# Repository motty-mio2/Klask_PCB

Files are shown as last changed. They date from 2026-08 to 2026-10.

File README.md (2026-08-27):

# Klask PCB

This repository contains the KiCad project files for **Klask PCB**, a custom Arduino Uno R3 shield designed to control stepper motors and limit switches for manipulating a **Klask** board game.

## Overview

**Klask PCB** is a hardware interface designed to automate or robotize the board game "Klask". It uses stepper motors to move the game magnets under the board. 

The shield drives two stepper motors (X and Y axes) using Pololu-style DRV8825 stepper driver modules and processes signals from homing limit switches to align the axes. Additionally, it integrates a power sense circuit to detect external 12V supply and is powered efficiently via a USB-PD Trigger Module.

---

## Features

- **Dual Axis Control**: Supports two DRV8825 stepper motor driver modules for X and Y axes.
- **Homing Support**: Hardware inputs for X and Y axis limit switches to perform auto-calibration (0-point homing).
- **USB-PD Powered**: Powered via an external 12V supply using a USB-PD Trigger Module.
- **Power Detection (Power Sense)**: Built-in voltage divider and noise-filtering circuit to safely detect whether the 12V motor power supply is active using the Arduino `D10` pin.
- **Visual Indicator**: LED indicator to show the status of the 12V power supply.
- **Minimalist Arduino Shield**: Uses only the Digital headers (10-pin and 8-pin) of the Arduino Uno R3 to minimize interference and pin usage.

---

## Bill of Materials (BOM)

Below is the list of components required to assemble the Klask PCB.

| Component | Designator | Qty | Description / Footprint |
| --- | --- | --- | --- |
| **DRV8825 Stepper Driver Module** | A1, A2 | 2 | Pololu Breakout board style stepper driver |
| **Arduino UNO R3** | A3 | 1 | Microcontroller board (acts as base) |
| **USB-PD Trigger Module** | — | 1 | Set to 12V output mode |
| **10-pin Pin Header** | — | 1 | 2.54mm pitch (for Arduino Digital High header) |
| **8-pin Pin Header** | — | 1 | 2.54mm pitch (for Arduino Digital Low header) |
| **8-pin Pin Socket** | — | 4 | 2.54mm pitch (sockets for DRV8825 modules) |
| **LED** | D1 | 1 | 3mm THT LED (Power/12V Status Indicator) |
| **2.54mm Terminal Block** | J1, J2, J3, J4, J5, SW4, SW5 | 7 | XY308-2.54-2P (For MotXA, MotXB, MotYA, MotYB, 12V, SWX, SWY) |
| **510 Ω Resistor** | R1 | 1 | THT Resistor (LED current limiting) |
| **180 Ω Resistor** | R2 | 1 | THT Resistor (Power sensing voltage divider) |
| **0.1 µF Capacitor** | C1 | 1 | Ceramic Capacitor THT (Power sense noise filter) |
| **100 µF Capacitor** | C3, C4 | 2 | Electrolytic Capacitor THT (Motor power decoupling) |

*Note: SW2 (SW_A) and SW3 (SW_B) are present on the PCB layout for potential UI expansion but are not populated in this build.*

---

## Pin Mapping

The Arduino Uno R3 digital pins are mapped to the stepper drivers, limit switches, and power sense circuit as follows:

### Stepper Motor Drivers (DRV8825)
| Signal Name | Arduino Uno Pin | DRV8825 Pin | Description |
| --- | --- | --- | --- |
| `/MX_STEP` | `D8` | `STEP` (A1) | X-axis step control pulse |
| `/MX_DIR` | `D9` | `DIR` (A1) | X-axis rotation direction |
| `/MY_STEP` | `D4` | `STEP` (A2) | Y-axis step control pulse |
| `/MY_DIR` | `D5` | `DIR` (A2) | Y-axis rotation direction |
| `/nEN` | `D3` | `~{RST}`, `~{SLP}` (A1, A2) | Driver enable (Reset / Sleep control) |
| `/M0` | `D0 / RX` | `M0` (A1, A2) | Microstep configuration bit 0 |
| `/M1` | `D1 / TX` | `M1` (A1, A2) | Microstep configuration bit 1 |
| `/M2` | `D2` | `M2` (A1, A2) | Microstep configuration bit 2 |

### Limit Switches & Sensors
| Signal Name | Arduino Uno Pin | PCB Connector | Description |
| --- | --- | --- | --- |
| `/SW_X` | `A5` (Digital I/O) | `SW4` | X-axis homing limit switch (Active Low) |
| `/SW_Y` | `A4` (Digital I/O) | `SW5` | Y-axis homing limit switch (Active Low) |
| `GND` | `GND` | `SW4`, `SW5` | Common Ground for switches |

### Power Sense & Feedback
| Signal Name | Arduino Uno Pin | Related Parts | Description |
| --- | --- | --- | --- |
| `/A0` | `D10` | `D1`, `R1`, `R2`, `C1` | Input pin to sense if 12V is connected (HIGH = 12V Present) |

---

## Hardware Connection & Assembly

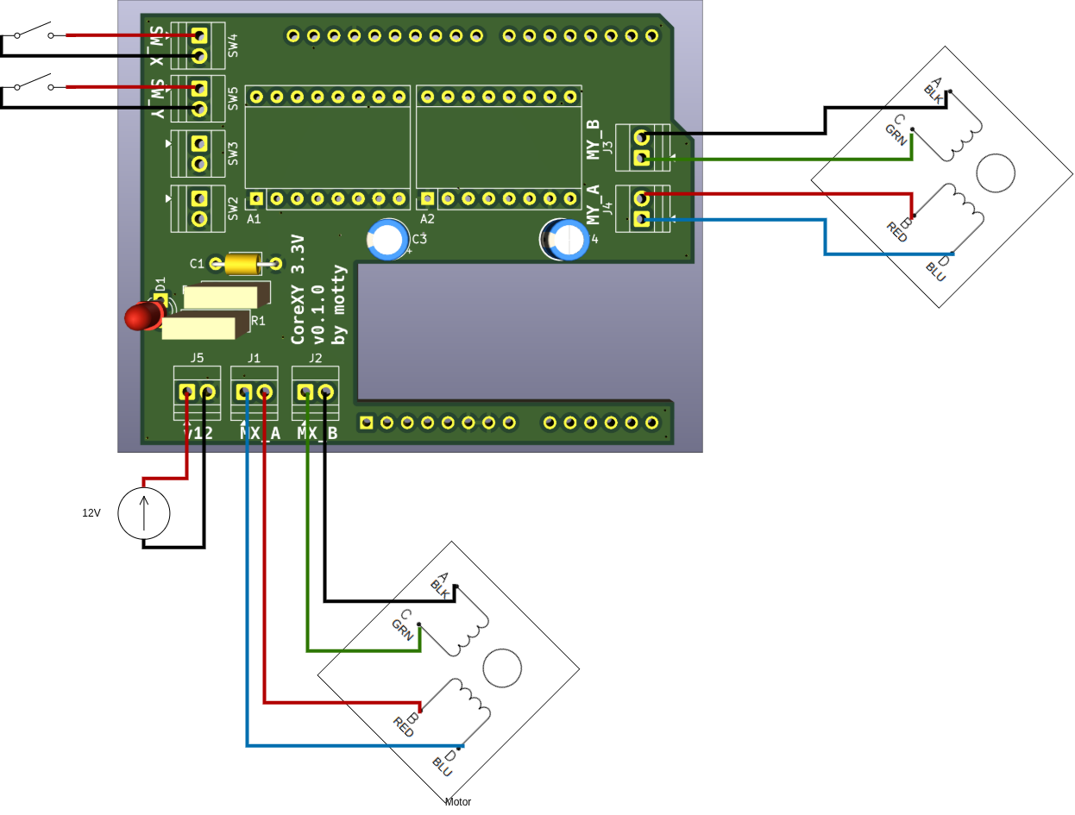
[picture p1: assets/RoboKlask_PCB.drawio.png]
Conceptual Wiring Diagram


1. **Terminal Blocks Wiring**:
   - **`J5` (12V Input)**: Connect the 12V and GND outputs from the **USB-PD Trigger Module**.
   - **`J1` & `J2`**: Connect to the X-axis stepper motor coils (Phase A to `J1`, Phase B to `J2`).
   - **`J3` & `J4`**: Connect to the Y-axis stepper motor coils (Phase A to `J3`, Phase B to `J4`).
   - **`SW4` & `SW5`**: Connect to the X-axis and Y-axis limit switches.
2. **Arduino Uno Mounting**:
   - Solder the 10-pin and 8-pin male headers to the digital side of the shield.
   - Solder the power sense circuit parts (`D1`, `R1`, `R2`, `C1`) and decoupling capacitors (`C3`, `C4`).
   - Stack the shield onto the Arduino Uno R3.
3. **Stepper Drivers**:
   - Solder the 8x4 female pin sockets onto the shield.
   - Insert the DRV8825 stepper driver modules into the sockets. Make sure the orientation is correct (VMOT/GND pin alignment).

---

## License

This project is licensed under the **CC BY-SA 4.0** (Creative Commons Attribution-ShareAlike 4.0 International) license. Feel free to share, copy, and modify, provided appropriate credit is given and any derivative works are distributed under the same license.

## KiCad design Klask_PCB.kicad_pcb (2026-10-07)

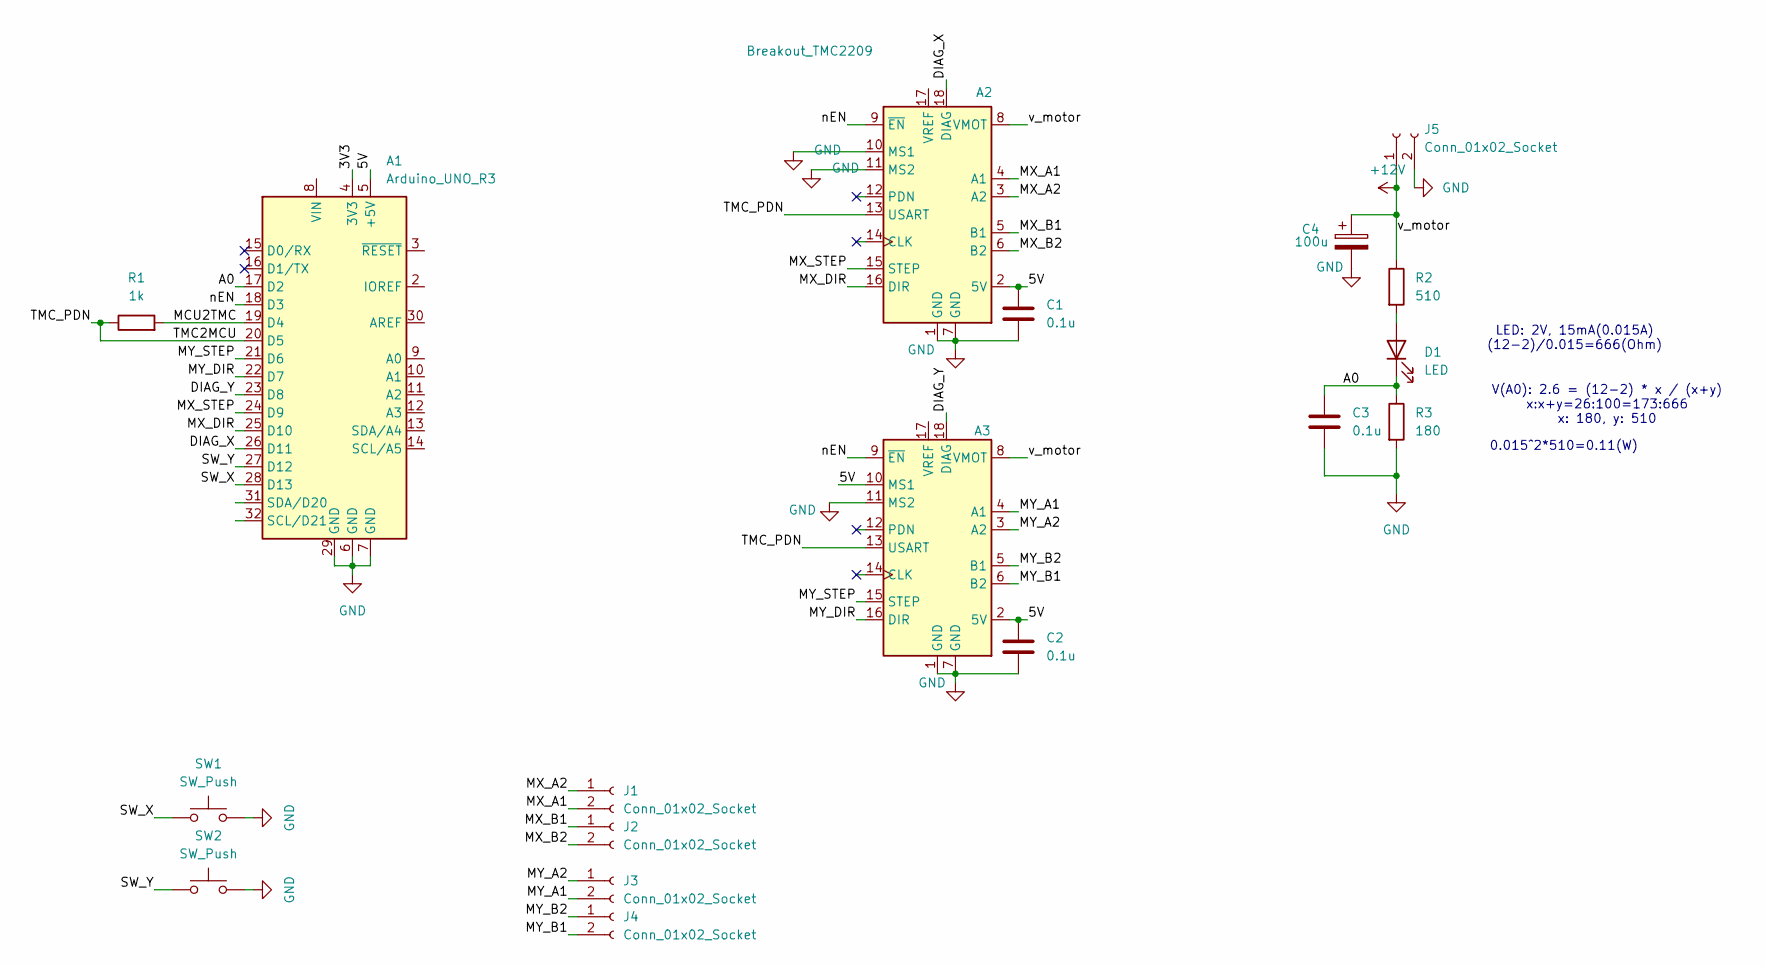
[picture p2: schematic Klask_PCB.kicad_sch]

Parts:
A1: Arduino_UNO_R3; Arduino_UNO_Q
A2: Breakout_TMC2209; TMC2209
A3: Pololu_Breakout_DRV8825; TMC2209
C1, C2, C3: 0.1u; C_Axial_L3.8mm_D2.6mm_P7.50mm_Horizontal
C4: 100u; CP_Radial_D5.0mm_P2.50mm
D1: LED; LED_D3.0mm
J1, J2, J3, J4, J5: Conn_01x02_Socket; TerminalBlock_Xinya_XY308-2.54-2P_1x02_P2.54mm_Horizontal
R1: 1k; R_Box_L8.4mm_W2.5mm_P5.08mm
R2: 510; R_Box_L8.4mm_W2.5mm_P5.08mm
R3: 180; R_Box_L8.4mm_W2.5mm_P5.08mm
SW1, SW2: SW_Push; TerminalBlock_Xinya_XY308-2.54-2P_1x02_P2.54mm_Horizontal

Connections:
+12V: A2.8 (VMOT), A3.8 (VMOT), C4.1, J5.1, R2.1
/3V3: A1.4 (3V3)
/5V: A1.5 (+5V), A2.2 (5V), A3.2 (5V), A3.10 (MS1), C1.1, C2.1
/A0: A1.17 (D2), C3.1, D1.1 (K), R3.1
/DIAG_X: A1.26 (D11), A2.18 (DIAG)
/DIAG_Y: A1.23 (D8), A3.18 (DIAG)
/MCU2TMC: A1.19 (D4), R1.2
/MX_A1: A2.4 (A1), J1.2
/MX_A2: A2.3 (A2), J1.1
/MX_B1: A2.5 (B1), J2.1
/MX_B2: A2.6 (B2), J2.2
/MX_DIR: A1.25 (D10), A2.16 (DIR)
/MX_STEP: A1.24 (D9), A2.15 (STEP)
/MY_A1: A3.4 (A1), J3.2
/MY_A2: A3.3 (A2), J3.1
/MY_B1: A3.6 (B2), J4.2
/MY_B2: A3.5 (B1), J4.1
/MY_DIR: A1.22 (D7), A3.16 (DIR)
/MY_STEP: A1.21 (D6), A3.15 (STEP)
/SW_X: A1.28 (D13), SW1.1
/SW_Y: A1.27 (D12), SW2.1
/TMC2MCU: A1.20 (D5), A2.13 (USART), A3.13 (USART), R1.1
/nEN: A1.18 (D3), A2.9 (~EN), A3.9 (~EN)
GND: A1.6 (GND), A1.7 (GND), A1.29 (GND), A2.1 (GND), A2.7 (GND), A2.10 (MS1), A2.11 (MS2), A3.1 (GND), A3.7 (GND), A3.11 (MS2), C1.2, C2.2, C3.2, C4.2, J5.2, R3.2, SW1.2, SW2.2
unnamed: D1.2 (A), R2.2

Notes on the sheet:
LED: 2V, 15mA(0.015A) (12-2)/0.015=666(Ohm)
0.015^2*510=0.11(W)
V(A0): 2.6 = (12-2) * x / (x+y) x:x+y=26:100=173:666 x: 180, y: 510

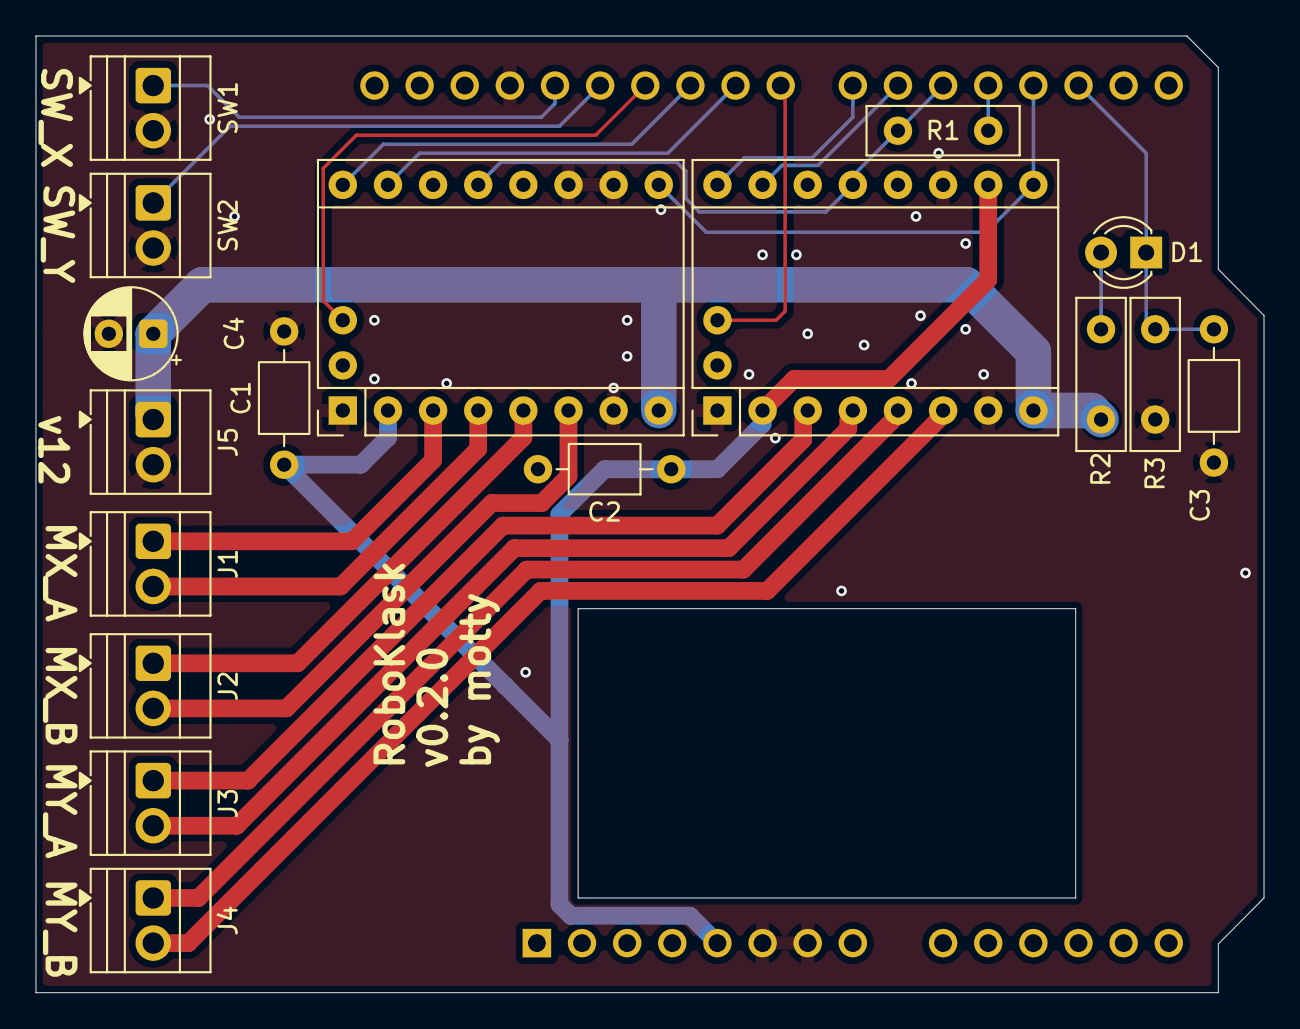
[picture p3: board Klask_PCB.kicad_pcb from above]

Board: 2 copper layers, 69.1 x 53.8 mm, 18 parts (1 on the bottom side), 24 nets.

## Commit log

2026-05-30 ci: split workflow into ERC check and PDF export
    - kicad-erc.yml: ERC/DRC checks on push and PR to main
    - kicad-export.yml: PDF/gerber/image export (ERC/DRC disabled)
2026-05-30 ci: export both top and bottom PCB images
2026-05-30 ci: use kicad/kicad:10.0 container with just
    Replace actions-for-kicad with kicad/kicad:10.0 Docker image and
    setup-just to run justfile recipes directly. Added gerbers, image
    export recipes to justfile.
2026-10-07 fix pin assign
    [Klask_PCB.kicad_pcb, Klask_PCB.kicad_sch]
2026-10-07 update ver
    [Klask_PCB.kicad_pcb]
